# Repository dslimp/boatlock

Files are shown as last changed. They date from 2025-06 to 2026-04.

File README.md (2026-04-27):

# BoatLock

BoatLock is an ESP32-S3 anchor-hold controller with a Flutter companion app.
The current development target is a single bench board running the main anchor
runtime, BLE phone control, onboard BNO08x heading, GNSS telemetry, manual
deadman control, hardware setup, and BLE OTA firmware update flows.

Current firmware release: `0.2.0`

## What It Does

- Saves the current GNSS position as an anchor point.
- Holds position around the saved point using GNSS distance and onboard BNO08x
  heading.
- Supports phone manual control through the same deadman path planned for a
  future external BLE controller.
- Drives the thruster with PWM plus two direction pins.
- Drives steering through a DRV8825-compatible STEP/DIR driver.
- Streams compact BLE telemetry to the app and mirrors firmware logs over the
  BLE log characteristic.
- Supports hardware setup operations from the app: stepper tuning, compass
  controls, and BLE OTA firmware update.
- Provides deterministic on-device HIL scenarios (`SIM_*`, `S0..S19`) for
  regression checks without relying on live sensors.

The BLE protocol is documented in [docs/BLE_PROTOCOL.md](docs/BLE_PROTOCOL.md).

## Repository Layout

- `boatlock/` - ESP32-S3 firmware, built with PlatformIO.
- `boatlock_ui/` - Flutter app for Android, macOS, and other Flutter targets.
- `docs/` - protocol, hardware, release, and powered-bench notes.
- `tools/hw/nh02/` - tracked hardware-bench wrappers for flashing, OTA, and
  Android BLE smoke checks.
- `tools/android/` - Android app build and smoke helpers.
- `tools/sim/` - offline anchor simulation harness.

## Current Bench Hardware

`boatlock/main.cpp` is the source of truth for the active pinout.

| Function | ESP32-S3 pin | Notes |
| --- | ---: | --- |
| GPS RX | GPIO17 | connect GPS TX |
| GPS TX | GPIO18 | connect GPS RX |
| BNO08x UART-RVC RX | GPIO12 | connect BNO08x RVC TX/SDA |
| BNO08x reset | GPIO13 | firmware reset pulse |
| BNO08x P0/PS0 | 3V3 | selects UART-RVC |
| BNO08x P1/PS1 | GND | selects UART-RVC |
| Thruster PWM | GPIO7 | PWM output |
| Thruster direction | GPIO8, GPIO10 | H-bridge direction inputs |
| Steering DRV8825 STEP | GPIO6 | STEP input |
| Steering DRV8825 DIR | GPIO16 | DIR input |
| BOOT anchor-save button | GPIO0 | debounced long-press |
| STOP button | GPIO15 | hardware stop / pairing window |

The steering geometry is set for the Vanchor gearbox:

- motor steps per revolution: `200`
- gearbox ratio: `36:1`
- output steps per steering revolution: `7200` (default)
- default `StepMaxSpd`: `1200`
- default `StepAccel`: `800`

Adjust `StepSpr` in firmware settings for DRV8825 microstepping (`7200 × microstep factor`).

If the DRV8825 `MODE0/MODE1/MODE2` pins are strapped for microstepping, the
mechanical speed is divided by that microstep factor unless the geometry and
speed limits are intentionally retuned.

Complete the powered checks before connecting real motor load:

- [docs/POWERED_BENCH_CHECKLIST.md](docs/POWERED_BENCH_CHECKLIST.md)
- [docs/STEERING_DRIVER_INTAKE.md](docs/STEERING_DRIVER_INTAKE.md)
- [docs/BRUSHED_MOTOR_DRIVER_INTAKE.md](docs/BRUSHED_MOTOR_DRIVER_INTAKE.md)

## Firmware Build

Use PlatformIO from `boatlock/`.

```bash
cd boatlock
pio run -e esp32s3
```

Useful environments:

- `esp32s3` - normal firmware. It includes BLE OTA and setup commands.
- `esp32s3_acceptance` - bench acceptance firmware with dev/HIL sensor
  injection enabled.
- `esp32s3_bno08x_sh2_uart` - explicit SH2-UART compass target when that wiring
  is under test.

## Flashing And OTA

Normal firmware update for the moved hardware is phone-bridged BLE OTA through
the production app:

```bash
cd boatlock
pio run -e esp32s3
cd ..
tools/hw/nh02/android-run-app-check.sh \
  --ota \
  --ota-firmware boatlock/.pio/build/esp32s3/firmware.bin \
  --wait-secs 1800
```

Use the longer OTA wait when BLE discovery may be cold. The wrapper timeout
starts before scan/connect and can otherwise expire during an active transfer.

USB flash on the `nh02` bench is the seed/recovery path:

```bash
tools/hw/nh02/flash.sh
```

## Flutter App

The app wrappers build one release app. Setup controls are part of that app and
stay hidden during normal use; open Settings and enable `Настройка оборудования`
to show stepper tuning, compass rows, and firmware OTA.

Android build:

```bash
tools/android/build-app-apk.sh
```

macOS build:

```bash
tools/macos/build-app.sh
```

Run from source:

```bash
cd boatlock_ui
flutter pub get
flutter run
```

## Validation

Firmware tests:

```bash
cd boatlock
platformio test -e native
```

Flutter checks:

```bash
cd boatlock_ui
flutter test
flutter analyze
```

High-signal targeted checks used during bench work:

```bash
cd boatlock
platformio test -e native -f test_settings -f test_runtime_ble_command_log -f test_ble_command_handler -f test_stepper_control -f test_runtime_motion

cd ../boatlock_ui
flutter test test/settings_page_test.dart
flutter test test/settings_page_setup_ui_test.dart
```

Android production-app manual smoke on `nh02`:

```bash
tools/hw/nh02/android-run-app-check.sh --manual --wait-secs 130
```

This sends zero-throttle `MANUAL_TARGET`, observes `MANUAL`, sends `MANUAL_OFF`,
and verifies the firmware returns to a quiet mode. It is not a powered thrust
test.

## Runtime Rules

- Heading comes only from onboard BNO08x UART-RVC frames.
- Control GNSS is hardware GPS only; phone GPS is telemetry/UI fallback and does
  not pass the anchor-control quality gate.
- `ANCHOR_ON` requires a saved anchor point, fresh onboard heading, and GNSS
  quality.
- Manual control uses atomic `MANUAL_TARGET:<angleDeg>,<throttlePct>,<ttlMs>`
  plus `MANUAL_OFF`, with `angleDeg=-90..90` across the steering arc.
- Runtime faults and STOP enter safe quiet output; they do not automatically
  resume Anchor or Manual.
- BLE security is owner-secret based; paired devices must wrap control commands
  in `SEC_CMD`.

## License

This project is licensed under the terms of the [MIT License](LICENSE).

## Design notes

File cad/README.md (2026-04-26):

# BoatLock CAD

This directory contains printable and inspectable mechanical models for
BoatLock bench and ground-simulator hardware.

## FreeCAD MCP

BoatLock CAD work uses the `neka-nat/freecad-mcp` server:

- MCP package: <https://github.com/neka-nat/freecad-mcp>
- FreeCAD addon path on this workstation:
  `~/Library/Application Support/FreeCAD/v1-1/Mod/FreeCADMCP`
- RPC endpoint when FreeCAD is running: `127.0.0.1:9875`
- Codex MCP server command: `/Users/user/.local/bin/uvx freecad-mcp`

FreeCAD must be running for MCP operations that inspect or mutate the live
model. The addon settings should keep `auto_start_rpc=true`; verify with:

```bash
python3 tools/cad/freecad_mcp_smoke.py
```

Headless, repeatable exports should stay script-driven and committed next to
the model source. For the ground trike:

```bash
cad/ground_trike/export_freecad.sh
```

## Modeling Rules

- Keep source models in text form where practical: FreeCAD Python, OpenSCAD, or
  small structured config files.
- Generated `.FCStd`, STL, screenshots, and temporary mesh outputs belong under
  each model's `out/` directory unless they are intentionally promoted.
- Model load paths explicitly: wheel loads should go into axles, bearings,
  forks, brackets, and deck screws, not motor shafts or printed cosmetic ribs.
- Include reference solids for motors, wheels, bearings, screws, shafts, and
  steering stops before treating a model as printable.
- Print/export scripts must report dimensions and solid-count checks.

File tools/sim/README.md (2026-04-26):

# Anchor Simulator

`tools/sim` provides an offline simulation harness for Anchor control hardening.

## What it does

- feeds synthetic GNSS measurements (`lat/lon/time/hdop/sats`) into control logic
- computes control outputs (`thrust_pct`, heading alignment effects)
- simulates boat drift and actuator response
- reports quality metrics:
  - `time_in_deadband_pct`
  - `p95_error_m`
  - `max_error_m`
  - `p95_heading_error_deg`
  - `max_heading_error_deg`
  - `p95_yaw_rate_dps`
  - `max_yaw_rate_dps`
  - `p95_heading_inertia_lag_deg`
  - `p95_environment_yaw_accel_dps2`
  - `steering_jammed_time_pct`
  - `steering_backlash_crossings_per_min`
  - `thrust_while_misaligned_time_pct`
  - `control_saturation_time_pct`
  - `num_thrust_direction_changes_per_min`
  - `invalid_thrust_count`
  - `invalid_motor_count`
  - `invalid_distance_count`
  - `min_battery_voltage_v`
  - `max_motor_current_a`
  - `max_motor_temp_c`
  - `motor_current_limited_time_pct`
  - `motor_thermal_derated_time_pct`
  - `motor_driver_deadband_time_pct`
  - `wake_event_time_pct`
  - `chop_event_time_pct`
  - `wake_event_count`
  - `chop_event_count`

## Actuator Model

The simulator keeps the controller command (`thrust_pct`) separate from applied
thrust. Steering/yaw and applied thrust pass through offline actuator models.
The steering model supports:

- finite steering response rate
- backlash on steering reversal
- static wrong-zero offset
- scheduled jam windows

Heading changes then pass through a yaw-rate state with acceleration limiting,
damping, and environmental yaw acceleration. This keeps steering commands from
turning the simulated boat instantly and lets off-axis wind/current/wake/chop
forcing perturb heading without changing firmware runtime behavior.

Applied thrust passes through a brushed motor model with:

- driver deadband
- first-order motor response
- battery voltage sag from internal resistance
- current limiting
- thermal accumulation, cooling, and derating

## Catalog World Model

Data-backed scenarios can include a `boat` block with loaded mass, submerged
drag, and above-water windage inputs. Current and wind/gust forcing use a
quadratic drag approximation, then divide force by loaded mass to get
acceleration. Wave forcing remains a bounded disturbance term scaled by loaded
mass until water-log data exists. Scenario `environment.events` can add explicit
`wake` or `chop` packets with start time, duration, height, period, and
direction; reports expose their event time/count and yaw/rocking effects.

## Scenarios (minimum set)

1. `calm_good_gps`
2. `constant_current`
3. `gusts`
4. `wake_steering_backlash`
5. `short_steep_chop`
6. `gnss_dropout`
7. `poor_hdop`
8. `position_jumps`
9. `comm_loss`
10. `nan_data`

## Optional RF Water Scenarios

The `russian` scenario set normalizes the first slice of
`tools/sim/research/environment_inputs.*` into runnable profiles:

1. `river_oka_normal_55lb`
2. `volga_spring_flow_80lb`
3. `rybinsk_fetch_55lb`
4. `ladoga_storm_abort`
5. `baltic_gulf_drift`

These scenarios add current, wind/gusts, wave-induced forcing, explicit wake or
chop event packets, and rocking/yaw metrics. Their reports also include the
loaded boat mass, water drag, and windage inputs used by the world model.
`ladoga_storm_abort` is intentionally modeled as an environment-abort case, not
as a normal anchor-hold success case.

Normalized scenario inputs live in
`tools/sim/scenarios/environment_profiles.json`. The research files under
`tools/sim/research/` remain source material and should not be treated as
directly executable simulator configuration.

Each normalized data-backed scenario includes a `provenance` object with the
source file, source candidate id, and confidence label. `run_sim.py` copies that
object into each matching JSON report result; built-in core scenarios omit it.

Known remaining gaps:

- hardware calibration after powered bench and water logs exist

## Run locally

```bash
python3 tools/sim/test_sim_core.py
python3 tools/sim/run_sim.py --check --json-out tools/sim/report.json
python3 tools/sim/run_sim.py --scenario-set russian --check --json-out tools/sim/russian_report.json
python3 tools/sim/test_soak.py
python3 tools/sim/run_soak.py --hours 6 --check --json-out tools/sim/soak_report.json
```

`--check` exits non-zero if scenario thresholds are violated (for CI gate).

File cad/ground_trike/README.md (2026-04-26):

# BoatLock Ground Trike Simulator V0

This is a first-pass printable CAD concept for a small ground simulator:

- two passive rear wheels
- one front wheel that steers and drives
- NEMA17 steering motor on the fixed deck
- 8 mm steering kingpin carried by two 608 bearings
- front drive motor mounted on the rotating fork

The model is intentionally parametric and conservative. It is not tied to a
specific purchased wheel or gearmotor yet. The FreeCAD script is the primary
source for generated `.FCStd` and STL artifacts; the OpenSCAD file is kept as a
simple text fallback.

## Drive Choice

Default CAD assumption: a 25GA / 25D class 12 V metal gearmotor mounted on the
front fork, driving the front wheel axle through a small belt or spur stage.

That is preferable to hanging the wheel directly on the motor shaft: the wheel
load goes into a 6 mm axle and fork bearings/holes, while the motor only
provides torque. A cheap TT motor can move a light bench model, but it is loose
and weak for a useful BoatLock simulator.

Suggested first motor class:

- 25GA370 or 25D metal gearmotor
- 12 V
- 100-200 rpm with a 65-80 mm rubber wheel
- encoder optional, not required for the current BoatLock manual drive path

The front motor wires need a slack service loop. Do not use unlimited steering;
limit the front fork mechanically to about +/-100 degrees unless a slip ring is
added.

## Steering Stack

The NEMA17 is fixed to the deck and should only transmit steering torque.
The front wheel load is not meant to go through the NEMA17 shaft.

Stack from top to bottom:

1. NEMA17 on deck, 31 mm M3 pattern
2. 5 mm to 8 mm shaft coupler
3. 8 mm steel kingpin or shoulder bolt
4. two 608 bearings in the printed carrier
5. printed front fork clamped to the kingpin

## FreeCAD Export

The FreeCAD path is primary for this model. It can be driven directly by
`freecadcmd` for repeatable exports, or through the repo-enabled FreeCAD MCP
server for live model inspection and iteration.

```bash
./export_freecad.sh
```

Outputs:

- `out/boatlock_ground_trike.FCStd`
- `out/stl/deck_plate.stl`
- `out/stl/steering_bearing_carrier.stl`
- `out/stl/front_fork_25ga.stl`
- `out/stl/rear_axle_block.stl`
- `out/stl/motor_cap_25ga.stl`

The `.FCStd` contains the assembly with translucent reference solids for the
front wheel, rear wheels, NEMA17, and front 25GA motor. The STL files are
exported as individual printable parts.

## OpenSCAD Fallback

Open `boatlock_ground_trike.scad` and set `part` to one of:

- `assembly`
- `deck_plate`
- `steering_bearing_carrier`
- `front_fork_25ga`
- `rear_axle_block`
- `motor_cap_25ga`

Export examples:

```bash
mkdir -p stl
openscad -o stl/deck_plate.stl -D 'part="deck_plate"' boatlock_ground_trike.scad
openscad -o stl/steering_bearing_carrier.stl -D 'part="steering_bearing_carrier"' boatlock_ground_trike.scad
openscad -o stl/front_fork_25ga.stl -D 'part="front_fork_25ga"' boatlock_ground_trike.scad
openscad -o stl/rear_axle_block.stl -D 'part="rear_axle_block"' boatlock_ground_trike.scad
openscad -o stl/motor_cap_25ga.stl -D 'part="motor_cap_25ga"' boatlock_ground_trike.scad
```

## Print Notes

- Print in PETG, ASA, PA, or PA-CF. Avoid PLA for the steering fork if it will
  see vibration, heat, or repeated crashes.
- Drill/ream functional holes after printing.
- Use M3 heat-set inserts or through screws with nuts for serviceable joints.
- Sand the 608 bearing pockets to fit the exact bearings.
- Print the front fork with enough perimeters that axle and kingpin holes are
  surrounded by solid material.

## BoatLock Firmware Caveat

This CAD switches the steering concept from the current 28BYJ-48 / ULN2003
bench path to NEMA17 mechanics. A normal NEMA17 driver path is not a drop-in
replacement for the current firmware wiring. Before connecting a powered NEMA17
driver, add and validate the real steering driver path in firmware and bench
acceptance.

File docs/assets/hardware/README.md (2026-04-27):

# Hardware Reference Images

These images are checked in so BoatLock pin assignments can be checked without
reopening the vendor page.

- `esp32-s3-lcd-2-pin-definition.png`: Waveshare ESP32-S3-LCD-2 header pinout.
- `esp32-s3-lcd-2-resource-introduction.png`: Waveshare ESP32-S3-LCD-2 onboard
  resources, including the microSD slot.

Source: Waveshare ESP32-S3-LCD-2 wiki/product material.

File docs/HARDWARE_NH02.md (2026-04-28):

# NH02 Hardware Bench

`nh02` (`192.168.88.61`) is the hardware bench host for the ESP32-S3 stand with GPS, display, compass, and stepper connected over USB.

## Board Reference

The current bench board is the Waveshare ESP32-S3-LCD-2 class board. Local
copies of the vendor pinout/resource images are kept under
`docs/assets/hardware/` so hardware checks do not depend on finding the product
page again.

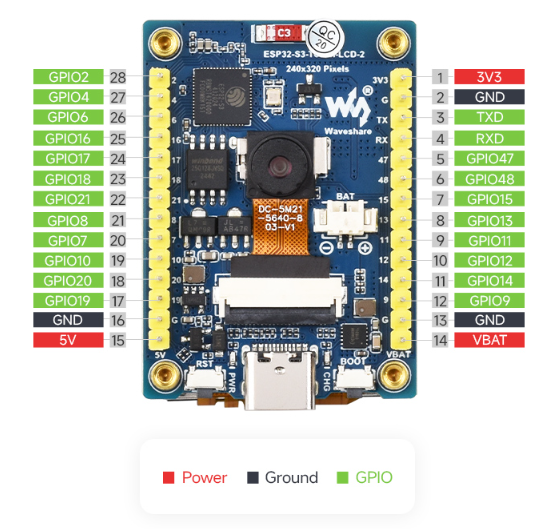
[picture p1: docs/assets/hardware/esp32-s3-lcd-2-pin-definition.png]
ESP32-S3-LCD-2 pin definition


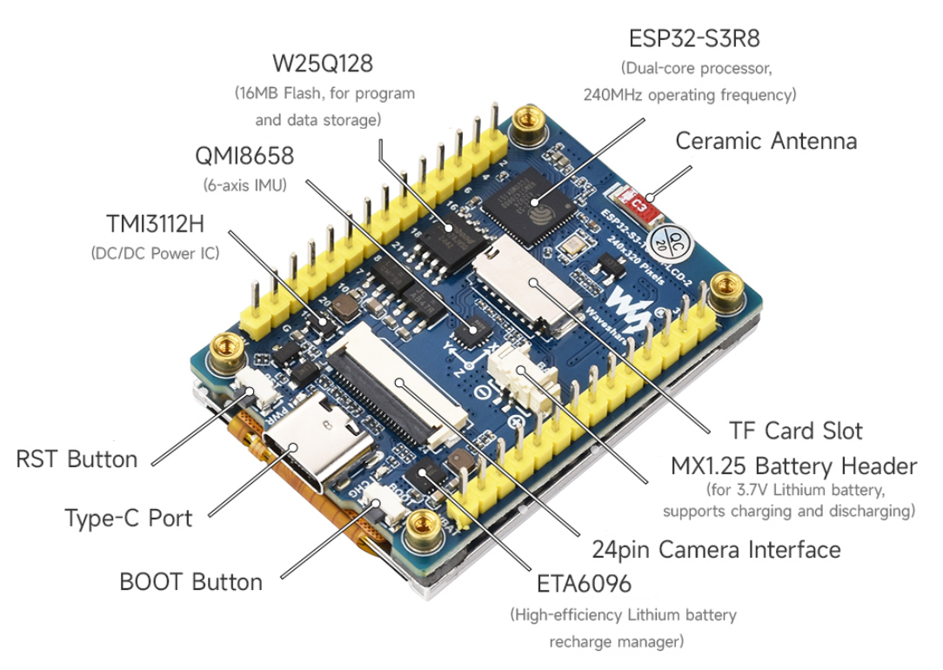
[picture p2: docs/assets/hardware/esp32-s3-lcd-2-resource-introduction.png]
ESP32-S3-LCD-2 resource introduction


## MicroSD runtime logging

- The onboard microSD slot is used for water-debug capture when a FAT-formatted
  card is inserted.
- Firmware writes JSONL files under `/boatlock/blNNNNN.jsonl`.
- Each file rotates at approximately `8 MiB`.
- If free space drops below approximately `8 MiB`, older BoatLock log files are
  deleted until approximately `16 MiB` is free or only the active file remains.
- Records include `type=session`, `type=log`, and 5 Hz `type=nav` snapshots with
  GNSS, heading, speed, anchor state, mode/status, motor, stepper, BLE, and
  `sd_dropped` counters.
- SD failure must not block control. The logger uses a bounded RAM queue and
  drops old lines when the card is absent, slow, or full.

## Remote runtime

- Remote USB device:
  - `/dev/serial/by-id/usb-Espressif_USB_JTAG_serial_debug_unit_98:88:E0:03:BA:5C-if00`
- Remote tool runtime:
  - `/opt/boatlock-hw/.venv`
- Remote runtime root:
  - `/opt/boatlock-hw`
- Remote RFC2217 service:
  - `boatlock-esp32s3-rfc2217.service`
- RFC2217 URL:
  - `rfc2217://192.168.88.61:4000?ign_set_control`

## Change boundary on nh02

- BoatLock-owned host changes are limited to:
  - `/opt/boatlock-hw/`
  - `/etc/systemd/system/boatlock-esp32s3-rfc2217.service`
- Android USB validation on `nh02` may additionally install the Ubuntu `adb` package through the tracked remote helper when that workflow is explicitly used.
- `install.sh` must be rerun after changing the tracked service or remote flash helper.
- `install.sh` must also be rerun after changing tracked remote Android helpers.
- `install.sh` restarts only `boatlock-esp32s3-rfc2217.service`; it does not touch unrelated services on `nh02`.

## Local workflow

- Install or refresh the remote bench runtime:
  - `tools/hw/nh02/install.sh`
- Bench moved-hardware OTA proof through the phone BLE bridge:
  - `tools/hw/nh02/deploy.sh`
  - this builds `esp32s3`, builds the ordinary release APK, refreshes Android helpers only, installs that exact APK, serves `firmware.bin`, uploads over BLE OTA, and waits for telemetry recovery
- Reuse already-built firmware/APK through the same bench automation path:
  - `tools/hw/nh02/deploy.sh --no-build`
- Seed or recover over USB through `nh02`:
  - `tools/hw/nh02/flash.sh`
- Flash the dev/HIL acceptance profile through `nh02`:
  - `tools/hw/nh02/flash.sh --profile acceptance`
- Build a firmware binary for BLE OTA:
  - `cd boatlock && pio run -e esp32s3 && shasum -a 256 .pio/build/esp32s3/firmware.bin`
- Upload firmware without ESP32 USB:
  - copy `firmware.bin` to the phone and use Settings -> `Файл на телефоне`, or
    publish a GitHub Release and use Settings -> `Последняя с GitHub`
- Low-level phone-bridged BLE OTA app-check, used by `deploy.sh`:
  - `tools/hw/nh02/android-run-app-check.sh --ota --ota-firmware boatlock/.pio/build/esp32s3/firmware.bin --wait-secs 1800`
- Public GitHub latest-release OTA app-check, same source as Settings -> `Последняя с GitHub`:
  - `tools/hw/nh02/android-run-app-check.sh --ota-latest-release --wait-secs 1800`
- Flash the current build without rebuilding:
  - `tools/hw/nh02/flash.sh --no-build`
- Run post-flash hardware acceptance:
  - `tools/hw/nh02/acceptance.sh`
- Run acceptance without forcing a reset first:
  - `tools/hw/nh02/acceptance.sh --no-reset`
- Open the serial monitor through RFC2217:
  - `tools/hw/nh02/monitor.sh`
- Check bridge/device status on the bench host:
  - `tools/hw/nh02/status.sh`
- Install or refresh Android USB tooling on `nh02`:
  - `tools/hw/nh02/android-install.sh`
- Check Android USB and `adb` visibility on `nh02`:
  - `tools/hw/nh02/android-status.sh`
- Install the normal production app APK on the `nh02` phone:
  - `tools/hw/nh02/android-install-app.sh`
- Enable Android ADB over Wi-Fi after initial USB discovery:
  - `tools/hw/nh02/android-wifi-debug.sh`
- Android smoke/check wrappers use ADB Wi-Fi by default when no `--serial` is
  passed. Set `BOATLOCK_NH02_ANDROID_WIFI_ADB=0` to force the default `adb`
  target selection.
- Build, install/update, and run the Android BLE smoke app through `nh02`:
  - `tools/hw/nh02/android-run-smoke.sh`
- Build, install/update, and run the Android BLE reconnect smoke app through `nh02`:
  - `tools/hw/nh02/android-run-smoke.sh --reconnect --wait-secs 130`
- Build, install/update, and prove phone recovery after ESP32 reboot:
  - `tools/hw/nh02/android-run-smoke.sh --esp-reset --wait-secs 130`
- Build, install/update, and prove compass calibration command delivery:
  - `tools/hw/nh02/android-run-app-check.sh --compass --wait-secs 130`
- Build, install/update, and prove BLE-visible hardware GPS fix:
  - `tools/hw/nh02/android-run-app-check.sh --gps --wait-secs 180`
- Run the full standard on-device HIL suite on the bench using the normal
  release firmware profile:
  - `tools/hw/nh02/run-sim-suite.sh`
- Run the smoke app without reinstalling the APK:
  - `tools/hw/nh02/android-run-smoke.sh --no-install`

## Profile-Aware Gate

Firmware command-scope enforcement is implemented in the shared BLE command
path. The normal `esp32s3` firmware accepts release commands, including setup,
BLE OTA, and `SIM_*`. The `esp32s3_acceptance` firmware additionally accepts
dev/HIL sensor injection such as `SET_PHONE_GPS`.

The effective firmware profile must stay visible at every bench entry point:

- USB flash wrappers must print the effective PlatformIO environment and
  command-scope profile.
- `tools/hw/nh02/flash.sh` accepts the normal `esp32s3` environment by default
  and `--profile acceptance` only when dev/HIL injection is required.
- `tools/hw/nh02/acceptance.sh` must know which profile is flashed. Normal
  acceptance keeps `SIM_*`, setup, and BLE OTA available while external
  sensor-injection commands stay gated.
- `tools/hw/nh02/android-run-app-check.sh --ota` runs against the normal firmware
  and must prove post-update telemetry recovery.
- `tools/hw/nh02/android-run-app-check.sh --sim`, `--sim-suite`, and the smoke
  `sim` mode run against the normal firmware.
- `tools/hw/nh02/run-sim-suite.sh` is the standard full on-device HIL bench
  gate. It flashes the normal firmware, runs boot acceptance, then runs
  production-app `sim_suite`.
- `tools/hw/nh02/install.sh` must be rerun after changing any tracked remote
  helper that enforces or reports the selected profile.

Accepted flash profile selector:

- `--profile acceptance` or `BOATLOCK_PIO_ENV=acceptance` builds
  `esp32s3_acceptance`.

Accepted direct PlatformIO environments:

- `esp32s3`: normal firmware with setup, BLE OTA, and release commands.
- `esp32s3_acceptance`: bench profile with dev/HIL sensor injection enabled.
- `esp32s3_bno08x_sh2_uart`: normal command profile with SH2-UART compass
  support.
- `gpio_probe` and `uart_rvc_probe_rx12`: debug probe builds, not release
  artifacts.

`BOATLOCK_PIO_ENV` must name one of the accepted selectors above. An empty or
unknown value is a wrapper error and must not silently fall back to another
build.

Expected operator flow:

1. Use phone BLE OTA as the normal moved-hardware update path; use USB flash
   only to seed/recover the device.
2. Run USB-bench water-readiness checks against the normal firmware and verify
   external-injection commands are rejected without actuation.
3. Run phone BLE OTA proof with `tools/hw/nh02/deploy.sh`.
4. Run quick on-device HIL on the normal firmware with the standard `nh02`
   acceptance plus Android `sim` smoke/check path.
5. For the standard full on-device HIL suite, run
   `tools/hw/nh02/run-sim-suite.sh`; it flashes and validates the normal
   firmware before the suite.
6. Use `--profile acceptance` only when a test explicitly needs dev/HIL
   injection, then return to the normal firmware.

If `OTA_BEGIN` or `SIM_RUN` appears broken, check the printed profile first; the
wrappers are expected to fail loudly instead of silently running the wrong
profile.

## USB Seed/Recovery Deploy Path

1. Local `pio run -e esp32s3` builds the firmware.
2. `flash.sh` copies `bootloader.bin`, `partitions.bin`, and `firmware.bin` to `nh02`.
3. Remote helper `/opt/boatlock-hw/bin/boatlock-flash-esp32s3.sh` temporarily stops the RFC2217 bridge, flashes the ESP32-S3 with remote `esptool`, then starts the bridge again.
4. `acceptance.sh` optionally forces a clean reset, captures boot logs over RFC2217, checks required boot markers, and fails on fatal log patterns.

## BLE OTA Phone Bridge

1. Use this as the normal moved-hardware firmware update path after the ESP32 already runs firmware with BLE OTA support.
2. Seed or recover over USB only when the target lacks an OTA-capable image or cannot reconnect over BLE.
3. Operator path A: copy the built `firmware.bin` to the phone and use Settings -> `Файл на телефоне`.
4. Operator path B: publish a GitHub Release with `manifest.json` and `firmware-esp32s3.bin`, then use Settings -> `Последняя с GitHub`.
5. For a local file, the app computes SHA-256 before transfer. For GitHub, the app downloads and verifies the release manifest SHA-256 before transfer.
6. The app sends `OTA_BEGIN`, writes chunks to BLE characteristic `9abc`, then sends `OTA_FINISH`.
7. ESP32 validates byte count and SHA-256 before finalizing the OTA partition and rebooting. Disconnect or failed validation aborts without changing the active boot partition.
8. Bench automation may still use hidden URL/SHA runtime extras with `tools/hw/nh02/deploy.sh`; that is a validation shortcut only, not an operator UI path.
   The wrapper builds the normal firmware and ordinary release APK, refreshes Android helpers without requiring ESP32 USB, installs the exact APK, serves `firmware.bin` on `nh02`, exposes it to the phone with `adb reverse`, starts its runtime OTA check, and waits for post-reboot telemetry.
   When `--serial` is omitted, the wrapper enables and uses Android ADB Wi-Fi
   automatically.
9. Current BLE upload requests high connection priority, a larger MTU, and
   write-without-response for OTA chunks when Android and the characteristic
   support it; otherwise it falls back to acknowledged writes. Keep the wrapper
   timeout long enough for the slower fallback path.
10. After a successful `OTA_FINISH` write, ESP32 may reboot before the phone
   receives the `[OTA] finish ok` notify line. Treat the post-finish disconnect
   plus reconnect/telemetry recovery as the bench verdict; the log line is useful
   evidence when present, not the only success signal.
11. Do not keep ESP32 debug Wi-Fi OTA running as the normal persistent bench
    channel while BLE is active. On this ESP32-S3/Arduino/NimBLE stack,
    Wi-Fi+BLE coexistence requires Wi-Fi modem sleep and was not reliable enough
    for firmware flashing. Use Android ADB Wi-Fi to control the phone and BLE OTA
    from the phone to flash the ESP32.
12. The BLE log characteristic `78ab` mirrors firmware `logMessage()` serial
    lines generated while the phone is connected and subscribed, including
    `[BLE]` lines. Boot logs before a BLE connection still require RFC2217/USB
    serial capture.

## Android USB Path

1. Rerun `tools/hw/nh02/install.sh` after changing tracked Android helpers.
2. `tools/hw/nh02/android-install.sh` ensures `adb` exists on `nh02`.
3. `tools/hw/nh02/android-status.sh` checks whether the phone is visible over USB and whether `adb devices -l` sees it.
4. `tools/hw/nh02/android-install-app.sh` builds, copies, and installs the normal production app APK on the `nh02` phone without running a smoke/check probe.
5. `tools/hw/nh02/android-wifi-debug.sh` can switch the same phone to ADB TCP/IP and prints `android_wifi_serial=<ip>:5555`.
6. `tools/hw/nh02/android-run-smoke.sh` and
   `tools/hw/nh02/android-run-app-check.sh` call the Wi-Fi ADB helper
   automatically unless `BOATLOCK_NH02_ANDROID_WIFI_ADB=0` is set or an explicit
   `--serial` is passed.
7. Any Android smoke wrapper can still use explicit `--serial <ip>:5555` to
   prove install/logcat/debug control over Wi-Fi instead of USB.
8. `tools/hw/nh02/android-run-smoke.sh` copies the ordinary release app APK to `nh02`, installs or updates it with remote `adb`, launches a runtime check in the app, and waits for the `BOATLOCK_SMOKE_RESULT` log line.
9. `tools/hw/nh02/android-run-smoke.sh --reconnect --wait-secs 130` additionally waits for first telemetry, cycles phone Bluetooth through ADB, and requires telemetry recovery without restarting the app.
10. `tools/hw/nh02/android-run-smoke.sh --esp-reset --wait-secs 130` waits for first telemetry, resets the ESP32-S3 with the tracked remote reset helper, and requires telemetry recovery without restarting the app.
11. `tools/hw/nh02/android-run-app-check.sh --compass --wait-secs 130` sends safe compass setup commands (`COMPASS_CAL_START`, `COMPASS_DCD_AUTOSAVE_OFF`, `COMPASS_DCD_SAVE`) and requires device log acknowledgements.
12. `tools/hw/nh02/android-run-app-check.sh --gps --wait-secs 180` waits for production-app BLE telemetry with non-zero valid coordinates and GNSS quality `>0`; this can run while ESP32 is powered away from USB if BLE remains reachable.
13. `tools/hw/nh02/android-run-app-check.sh --sim-suite --wait-secs 1800` runs `SIM_LIST`, every listed scenario through `SIM_RUN:<id>,0`, polls `SIM_STATUS`, collects `SIM_REPORT`, and fails on any `pass:false`.
14. `tools/hw/nh02/run-sim-suite.sh` wraps the full bench flow around `--sim-suite`: helper install, target proof, release flash, boot acceptance, and production-app suite run.
15. `tools/hw/nh02/deploy.sh` is bench automation for firmware+APK OTA proof and verifies phone download, SHA-256 check, BLE upload, ESP32 reboot, and app telemetry recovery. Use `tools/hw/nh02/android-run-app-check.sh --ota --ota-firmware boatlock/.pio/build/esp32s3/firmware.bin --wait-secs 1800` only as the lower-level local-firmware OTA check. Use `tools/hw/nh02/android-run-app-check.sh --ota-latest-release --wait-secs 1800` to prove the public GitHub Release source used by the phone button.
16. If the phone appears only as `MTP` or a vendor USB device and not in `adb devices`, the cable path is alive but USB debugging is still off on the phone.
17. Status smoke recovery may clear `STOP_CMD` directly to `IDLE/WARN` after a
    zero-throttle manual recovery command without exposing a visible `MANUAL`
    telemetry frame. The wrapper must still send `MANUAL_OFF` cleanup and accept
    the recovered non-alert state.

## Xiaomi Install Note

- On the current Xiaomi test phone, the first `adb install` was blocked by MIUI policy with `INSTALL_FAILED_USER_RESTRICTED`.
- The tracked `adb install -r` update path succeeded after the phone-side MIUI flow was satisfied: Xiaomi account, inserted SIM card, and `Install via USB` approval.
- Treat first-install policy and later USB update as separate checkpoints; do not assume the first failure means all future `adb install -r` updates are blocked.

## Bench Bridge Path

- Runtime logs go through the persistent RFC2217 bridge on `nh02`.
- `monitor.sh` uses local `pyserial-miniterm` against the RFC2217 endpoint.
- If the monitor path fails, inspect `status.sh` before touching the USB device manually.
- BLE OTA through the phone is the normal no-USB firmware update path after the
  first OTA-capable image is present.
- Local phone-file OTA computes SHA-256 in the app before transfer. GitHub OTA
  verifies the release manifest SHA-256 before transfer. Do not add
  operator-facing arbitrary URL/SHA fields back to the Settings UI.
- The app wrappers build one release Android/macOS app. Setup controls are in
  that app and hidden behind the Settings `Настройка оборудования` switch. The
  one-button release OTA path resolves firmware through the latest GitHub
  Release for `dslimp/boatlock`. Local wrapper shortcuts:
  `tools/android/build-app-apk.sh` and `tools/macos/build-app.sh`.
- CI publishes one ready-to-install app artifact per platform:
  `flutter-android-apk/boatlock-app.apk` and
  `flutter-macos-app/boatlock-macos.zip`.
- macOS app local acceptance is covered by
  `tools/macos/acceptance.sh`. Use `--static-only` for bundle/signature/
  entitlement checks, `--artifact-zip boatlock-macos.zip` for a CI
  artifact, and `--manual` to open the app with the update checklist.
  Without BLE hardware this proves only bundle/runtime readiness, not OTA.
- Android app checks exercise the public GitHub latest-release path with
  `tools/hw/nh02/android-run-app-check.sh --ota-latest-release --wait-secs 1800`.
  This starts the normal app with runtime check extras and lets the app fetch
  `manifest.json` plus `firmware-esp32s3.bin` from the latest GitHub Release.
  Adding `--ota-firmware boatlock/.pio/build/esp32s3/firmware.bin` switches the
  same check into local temporary-manifest validation for unpublished firmware.
  Both modes still wait for post-reboot telemetry.
- Tagged releases publish `manifest.json` and `firmware-esp32s3.bin` with the
  same `esp32s3` and `release` constraints as the local manifest path. The
  fallback release metadata files are `BUILD_INFO-esp32s3.txt` and
  `SHA256SUMS-esp32s3.txt`.
- `tools/hw/nh02/flash.sh` stages `boot_app0.bin` and flashes it at `0xe000`, so a USB seed flash after prior OTA boots the freshly flashed `ota_0` image instead of a stale OTA slot.
- Keep the seed flash recoverable through USB. If a BLE OTA upload fails before `OTA_FINISH`, the current firmware remains active; if the app cannot reconnect, flash the normal firmware again through `tools/hw/nh02/flash.sh`.

## Compass Wiring

- Accepted bench compass transport is currently BNO08x UART-RVC.
- Current `nh02` wiring:
  - BNO08x `SDA/TX` -> ESP32-S3 `GPIO12`
  - BNO08x `RST` -> ESP32-S3 `GPIO13`
  - BNO08x `P0/PS0` -> `3V3`
  - BNO08x `P1/PS1` -> `GND`
  - UART baud `115200`
- SH2-UART DCD migration target:
  - BNO08x `TXO` -> ESP32-S3 `GPIO12`
  - BNO08x `RXI` -> ESP32-S3 `GPIO11`
  - BNO08x `RST` -> ESP32-S3 `GPIO13`
  - BNO08x `P0/PS0` -> `GND`
  - BNO08x `P1/PS1` -> `3V3`
  - build with `BOATLOCK_PIO_ENV=esp32s3_bno08x_sh2_uart`
- Full DCD/tare functionality is not accepted on the current RVC wiring. RVC can only prove command delivery with `ok=0`; SH2-UART acceptance needs the wiring above plus a fresh flash of the explicit SH2 target.
- `GPIO12` was verified by grounding the RX line and by reading live RVC frames with `uart_rvc_probe_rx12`.
- `GPIO13` was verified as reset by grounding the reset wire and watching `gpio_probe` transitions.
- Hardware acceptance requires `[COMPASS] ready=1 source=BNO08x-RVC rx=12 ... baud=115200` plus `[COMPASS] heading events ready`.
- The old ESP32-S3 I2C compass path is removed from production firmware. Historical failure notes are kept in `WORKLOG.md`, not as a fallback path.

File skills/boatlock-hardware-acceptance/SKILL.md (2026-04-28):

---
name: boatlock-hardware-acceptance
description: "Use for BoatLock real-hardware acceptance on nh02 after phone BLE OTA or recovery USB flashing, reading serial boot logs, checking sensor/bridge readiness, or preparing Android USB/BLE smoke tests against the hardware bench."
---

# BoatLock Hardware Acceptance

Use this skill when the task is about updating or validating the real ESP32-S3 hardware through phone BLE OTA, recovery USB flashing on `nh02`, or Android USB + BLE smoke against the bench.

## Read Only What You Need

- NH02 deploy/debug path and host boundary:
  - `docs/HARDWARE_NH02.md`
- Current BoatLock hardware/runtime invariants:
  - `skills/boatlock/references/firmware.md`
- BLE/app contract:
  - `skills/boatlock/references/ble-ui.md`
- Android USB + BLE workflow and current limits:
  - `references/android-ble.md`

## NH02 Acceptance Workflow

1. Refresh the bench runtime if tracked helpers or service units changed:
   - `tools/hw/nh02/install.sh`
2. Update current firmware when needed:
   - operator path A: Android Settings -> `Файл на телефоне`
   - operator path B: Android Settings -> `Последняя с GitHub`
   - bench automation path: `tools/hw/nh02/deploy.sh`
   - reuse already-built firmware/APK through the same path: `tools/hw/nh02/deploy.sh --no-build`
   - recovery/seed path only: `tools/hw/nh02/flash.sh` or `tools/hw/nh02/flash.sh --no-build`
3. Run hardware acceptance:
   - `tools/hw/nh02/acceptance.sh`
4. For microSD logger acceptance, insert a FAT-formatted card before boot and
   verify `[SD] logger ready=1`, display redraws, `/boatlock/*.jsonl` growth,
   and `sd_dropped` stays bounded under the expected log rate.
5. If acceptance fails, inspect:
   - `tools/hw/nh02/status.sh`
   - `tools/hw/nh02/monitor.sh`

## Android USB + BLE Smoke Workflow

1. Check USB device visibility:
   - `tools/android/status.sh`
   - or `tools/hw/nh02/android-status.sh` when the phone is attached to `nh02`
2. Optionally switch the phone to ADB Wi-Fi after USB proof:
   - `tools/hw/nh02/android-wifi-debug.sh`
   - Android smoke/check wrappers auto-enable and use ADB Wi-Fi when no
     `--serial` is passed; set `BOATLOCK_NH02_ANDROID_WIFI_ADB=0` only when USB
     `adb` must be forced.
3. Build the ordinary release app APK:
  - `tools/android/build-app-apk.sh`
4. Install and run the phone check flow through the same release app:
   - `tools/android/run-smoke.sh`
   - or `tools/hw/nh02/android-run-smoke.sh` when the phone is attached to `nh02`
   - use `tools/hw/nh02/android-run-app-check.sh --manual --wait-secs 130`, `--status`, `--anchor`, `--sim`, `--reconnect`, or `--esp-reset` for production-app command/recovery flows
   - use `tools/hw/nh02/android-run-app-check.sh --sim-suite --wait-secs 1800` to run all listed on-device HIL scenarios through the production app on an already-flashed release profile
   - use `tools/hw/nh02/run-sim-suite.sh` for the standard full bench gate; it installs helpers, proves targets, flashes normal firmware, runs boot acceptance and `sim_suite`
   - use `tools/hw/nh02/android-run-app-check.sh --compass --wait-secs 130` after compass BLE command changes; it sends safe DCD setup commands and requires device-log acknowledgements
   - use `tools/hw/nh02/android-run-app-check.sh --gps --wait-secs 180` after GNSS live-telemetry changes or field GPS checks; it requires valid non-zero coordinates and `gnssQ > 0`
   - use `tools/hw/nh02/deploy.sh` after BLE OTA/app-delivery changes; it builds the normal firmware and release APK, refreshes Android helpers, installs the same release app, serves `firmware.bin` from `nh02`, uploads over BLE from the phone, and requires post-reboot telemetry recovery
  - use `tools/hw/nh02/android-run-app-check.sh --ota-latest-release --wait-secs 1800` to prove the public GitHub Release button source through the production app
  - use `tools/hw/nh02/android-run-app-check.sh --ota --ota-firmware boatlock/.pio/build/esp32s3/firmware.bin` only as the lower-level local-firmware OTA check when you need to bypass the build wrapper
   - pass a longer OTA wait such as `--wait-secs 1800` when BLE discovery may
     be cold or intermittent; the wrapper timeout includes scan/reconnect time
     before upload starts and can otherwise expire during an active transfer
   - use `tools/hw/nh02/android-run-smoke.sh --manual --wait-secs 130` after manual BLE protocol changes; this sends zero-throttle `MANUAL_TARGET`, verifies `MANUAL`, sends `MANUAL_OFF`, and verifies mode exit
   - use `tools/hw/nh02/android-run-smoke.sh --status --wait-secs 130` after phone-visible status/severity changes; this sends `STOP`, verifies `ALERT/STOP_CMD`, then clears through zero-throttle manual roundtrip
   - use `tools/hw/nh02/android-run-smoke.sh --sim --wait-secs 130` after `SIM_*` BLE/HIL changes; this starts realtime `S0`, verifies `SIM` mode, sends `SIM_ABORT`, then clears the safe hold through zero-throttle manual recovery
   - use `tools/hw/nh02/android-run-smoke.sh --anchor --wait-secs 130` after phone-visible anchor command, safety gate, or anchor telemetry changes; this sends `ANCHOR_ON`, verifies the bench-side safety denial, sends `ANCHOR_OFF`, and verifies the device did not enter `ANCHOR`
   - use `tools/hw/nh02/android-run-smoke.sh --reconnect --wait-secs 130` when reconnect behavior is the acceptance target
   - use `tools/hw/nh02/android-run-smoke.sh --esp-reset --wait-secs 130` when ESP32 reboot recovery is the acceptance target
   - do not use `--no-install` as acceptance unless the user explicitly waives exact APK installation proof for that run
5. If it fails, inspect:
  - device logcat around `BOATLOCK_SMOKE_RESULT`
  - `tools/hw/nh02/monitor.sh`
  - `tools/hw/nh02/status.sh`
  - `tools/hw/nh02/android-status.sh` when the phone is attached to `nh02` instead of the local workstation

## What Acceptance Proves

- Boot log is reachable over the tracked debug path.
- Bench hardware reports:
  - `BNO08x-RVC` ready on `rx=12 baud=115200`
  - live BNO08x UART-RVC heading frames
  - BNO08x reset pin `13` pulse on boot/retry
  - display ready
  - NVS settings load
  - BLE init + advertising
  - stepper config
  - STOP button init
  - GPS UART activity
- Fatal boot indicators such as panic/assert/advertising failure, Arduino `[E]` logs, `COMPASS lost`, or `COMPASS retry ready=0` are not present in captured logs.
- Compass acceptance requires `[COMPASS] heading events ready`; `[COMPASS] ready=1 source=BNO08x-RVC ...` alone is not sufficient.
- Do not count `[COMPASS] reset ... pulse=1` as recovery proof. Recovery is proven only by fresh heading frames after the pulse and a clean long acceptance capture.
- For compass-focused changes, use a longer capture such as `--seconds 180`; a short boot-only pass can miss delayed wiring or frame-loss failures.
- microSD logger acceptance requires real media proof. Compile success and a
  boot log alone do not prove `/boatlock/*.jsonl` creation, write cadence,
  rotation, or low-space deletion.

## What Acceptance Does Not Prove

- It does not prove BLE control flow end to end.
- Basic Android smoke proves BLE scan/connect and telemetry with known current protocol mode/status values only; it does not intentionally send actuation commands.
- Manual Android smoke proves exact APK install, BLE scan/connect/telemetry, zero-throttle `MANUAL_TARGET`, observed `MANUAL` mode, `MANUAL_OFF`, and observed mode exit. It is not a powered thrust test.
- Status Android smoke proves exact APK install, BLE scan/connect/telemetry, safe `STOP` command delivery, observed `ALERT/STOP_CMD`, and alert recovery through zero-throttle manual roundtrip. Recovery may clear directly to a non-alert `IDLE/WARN` frame without an observed intermediate `MANUAL` frame; still require `MANUAL_OFF` cleanup. It is not a powered thrust test.
- SIM Android smoke proves exact APK install, BLE scan/connect/telemetry, `SIM_RUN:S0,1`, observed `SIM` mode, `SIM_ABORT`, observed mode exit, and alert recovery through zero-throttle manual roundtrip. It is not a powered thrust test.
- Anchor Android smoke proves exact APK install, BLE scan/connect/telemetry, `ANCHOR_ON` delivery, observed `[EVENT] ANCHOR_DENIED` from the bench safety gate, `ANCHOR_OFF` cleanup, and no transition into `ANCHOR`. It is not a real anchor-hold quality test.
- Reconnect Android smoke proves exact APK install, first telemetry, host-triggered Bluetooth outage, and telemetry recovery without app restart.
- ESP reset Android smoke proves exact APK install, first telemetry, ESP32 reset through the tracked reset helper, and telemetry recovery without app restart.
- Compass Android smoke proves exact APK install, first telemetry, safe compass calibration command delivery, and device-log acknowledgement. On RVC wiring it proves routing only; it does not prove DCD success.
- GPS Android smoke proves exact APK install, BLE scan/connect/telemetry, valid non-zero coordinates, and GNSS quality `>0`. It does not prove anchor-control GNSS gate readiness unless `gnssQ=2` and anchor-specific acceptance also passes.
- OTA production-app check proves exact APK install, phone HTTP download via `adb reverse`, SHA-256 verification in the app, BLE OTA upload, ESP32 reboot, and telemetry recovery after the update. A post-`OTA_FINISH` disconnect plus reconnect/telemetry is acceptable even if the app misses the `[OTA] finish ok` notify before reboot. It does not prove bootloader or partition-table changes; those still need USB flash.
- Persistent bench wireless is Android ADB Wi-Fi to the phone plus BLE to ESP32.
  Direct ESP32 debug Wi-Fi OTA is a boot-window/debug path, not the normal
  persistent channel while BLE is active on the ESP32-S3 bench.
- BLE log characteristic `78ab` mirrors firmware serial log lines generated
  after the phone is connected/subscribed, including `[BLE]` lines. Use
  RFC2217/USB serial for pre-BLE boot logs.
- Android smoke does not prove real powered actuation or on-water hold quality.
- Full BNO08x DCD/tare acceptance requires the explicit `esp32s3_bno08x_sh2_uart` target plus SH2-UART wiring; do not count current RVC acceptance as DCD proof.
- It does not prove real anchor hold quality on water.
- It does not replace on-device `SIM_*` checks or offline simulation.
- It does not prove durable water-debug logging unless the FAT microSD card is
  inserted and checked after runtime.

## Current Commands

- Bench runtime refresh:
  - `tools/hw/nh02/install.sh`
- BLE OTA bench automation:
  - `tools/hw/nh02/deploy.sh`
  - `tools/hw/nh02/deploy.sh --no-build`
- Low-level BLE OTA app-check:
  - `tools/hw/nh02/android-run-app-check.sh --ota --ota-firmware boatlock/.pio/build/esp32s3/firmware.bin --wait-secs 1800`
- Public GitHub latest-release app-check:
  - `tools/hw/nh02/android-run-app-check.sh --ota-latest-release --wait-secs 1800`
- USB seed/recovery flash:
  - `tools/hw/nh02/flash.sh`
- Acceptance:
  - `tools/hw/nh02/acceptance.sh`
  - `tools/hw/nh02/acceptance.sh --no-reset`
  - `tools/hw/nh02/acceptance.sh --seconds 15 --log-out /tmp/boatlock-boot.log --json-out /tmp/boatlock-acceptance.json`
- Debug:
  - `tools/hw/nh02/status.sh`
  - `tools/hw/nh02/monitor.sh`
- Android:
  - `tools/hw/nh02/android-install-app.sh`
  - `tools/hw/nh02/android-run-app-check.sh`
  - `tools/hw/nh02/android-run-app-check.sh --manual --wait-secs 130`
  - `tools/hw/nh02/android-run-app-check.sh --status --wait-secs 130`
  - `tools/hw/nh02/android-run-app-check.sh --sim --wait-secs 130`
  - `tools/hw/nh02/android-run-app-check.sh --sim-suite --wait-secs 1800`
  - `tools/hw/nh02/android-run-app-check.sh --anchor --wait-secs 130`
  - `tools/hw/nh02/android-run-app-check.sh --compass --wait-secs 130`
  - `tools/hw/nh02/android-run-app-check.sh --gps --wait-secs 180`
  - `tools/hw/nh02/android-run-app-check.sh --ota --ota-firmware boatlock/.pio/build/esp32s3/firmware.bin`
  - `tools/hw/nh02/android-run-app-check.sh --ota --ota-firmware boatlock/.pio/build/esp32s3/firmware.bin --wait-secs 1800`
  - `tools/hw/nh02/android-run-app-check.sh --reconnect --wait-secs 130`
  - `tools/hw/nh02/android-run-app-check.sh --esp-reset --wait-secs 130`
  - `tools/hw/nh02/android-install.sh`
  - `tools/hw/nh02/android-status.sh`
  - `tools/hw/nh02/android-wifi-debug.sh`
  - `tools/hw/nh02/android-run-smoke.sh`
  - `tools/hw/nh02/android-run-smoke.sh --manual --wait-secs 130`
  - `tools/hw/nh02/android-run-smoke.sh --status --wait-secs 130`
  - `tools/hw/nh02/android-run-smoke.sh --sim --wait-secs 130`
  - `tools/hw/nh02/android-run-smoke.sh --anchor --wait-secs 130`
  - `tools/hw/nh02/android-run-smoke.sh --compass --wait-secs 130`
  - `tools/hw/nh02/android-run-smoke.sh --gps --wait-secs 180`
  - `tools/hw/nh02/android-run-smoke.sh --reconnect --wait-secs 130`
  - `tools/hw/nh02/android-run-smoke.sh --esp-reset --wait-secs 130`
  - `tools/hw/nh02/android-run-smoke.sh --no-install`
  - `tools/hw/nh02/run-sim-suite.sh`
  - `tools/android/status.sh`
  - `tools/android/build-app-apk.sh`
  - `tools/android/run-smoke.sh`

## Working Rules

- Keep host-side ownership limited to `/opt/boatlock-hw` and the tracked RFC2217 service.
- Default refactor cadence runs hardware acceptance after every fifteenth module, not after every low-risk module.
- Run acceptance immediately when the module touches hardware drivers, pinout, deploy/debug wrappers, actuator safety, BLE reconnect/install behavior, or another path where local tests cannot bound the risk.
- When acceptance is due on the USB bench path, run it right after the seed/recovery flash so the boot path stays part of the same validation slice.
- Preserve the documented order for the chosen path. For normal moved hardware that means target proof, firmware build, phone BLE OTA, telemetry recovery, then Android BLE checks. For USB bench recovery that means `install -> flash -> acceptance -> monitor/debug`.
- Do not treat a missing ESP32 USB serial path as a blocker for the normal phone BLE OTA path when the Android phone target is proven and BLE OTA can run.
- For phones attached to `nh02`, use the tracked `android-install.sh` and `android-status.sh` path before falling back to local `adb` assumptions.
- Use `tools/hw/nh02/android-install-app.sh` when the task is only to install the normal production app APK on the `nh02` phone without running a smoke/check probe.
- For Wi-Fi ADB acceptance, seed it from the tracked USB-visible phone with `android-wifi-debug.sh`, then run the same smoke wrapper with `--serial <ip>:5555`; `adb devices` alone is not enough.
- Record whether failure is in first install policy, later `adb install -r` update, app launch, or BLE runtime; do not collapse those into one generic "Android smoke failed" verdict.
- Treat `android-run-smoke.sh --no-install` as BLE-runtime proof only; it does not prove that the exact just-built APK was installed on the phone.
- If full smoke fails with `INSTALL_FAILED_USER_RESTRICTED`, stop on that blocker. Required phone-side fixes are `Install via USB`, Xiaomi/MIUI security install confirmation, and any account or policy prompts that gate ADB installs.
- A logged first-attempt `INSTALL_FAILED_USER_RESTRICTED` followed by canonical retry `Success` and a passing `BOATLOCK_SMOKE_RESULT` is not a blocker; record the retry but trust the terminal wrapper verdict.
- Do not interrupt a live flash, build, acceptance run, or phone smoke while it is still making forward progress.
- If a bench or phone wrapper fails, fix that wrapper before normalizing a manual fallback.
- If a bench or phone wrapper returns stale, wrong, or ambiguous data, fix the wrapper or its guidance before trusting the result.
- For bash wrappers that run under macOS bash 3.2 with `set -u`, do not expand an empty array directly as `"${ARGS[@]}"`; branch on `${#ARGS[@]}` before expanding optional args.
- If `tools/hw/nh02/flash.sh --no-build` fails because expected PlatformIO artifacts are missing, rerun canonical `tools/hw/nh02/flash.sh` instead of hand-copying or reconstructing artifacts.
- Do not replace a pending or slow acceptance or phone-smoke verdict with manual `monitor.sh` or `logcat` interpretation. Use those only as blocker-debug context.
- Before live mutation on `nh02` or an attached Android phone, prove the exact target first and keep the recovery path explicit.
- Prefer repo-tracked scripts and remote helpers over ad-hoc inline `ssh` write commands or hand-typed mutation chains.
- For BLE OTA rollouts after live-frame schema changes, remember that the new
  APK is installed before the old firmware is updated. Keep enough app-side
  parser bridge for the installed firmware to emit first telemetry and start
  OTA, then prove the bridge with `tools/hw/nh02/deploy.sh`.
- If acceptance or monitor output disagrees with docs, update docs in the same change.
- Record every meaningful bench validation stage in `WORKLOG.md`.

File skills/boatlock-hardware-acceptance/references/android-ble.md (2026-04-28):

# Android USB + BLE Notes

## Current Local Capability

- `adb` is installed locally.
- Flutter and Android SDK are present locally.
- Current repo has Android app code under `boatlock_ui/android`.
- Current repo does not have a ready `integration_test/` BLE end-to-end suite.

## NH02 Bench Capability

- `nh02` can also act as the Android USB host, not only as the ESP32-S3 host.
- Current moved-hardware firmware updates normally use the phone as the BLE OTA
  bridge. USB ESP32 flashing is only the seed/recovery path unless the task
  explicitly targets USB bench flashing.
- Use `tools/hw/nh02/android-install.sh` to ensure `adb` exists on `nh02`.
- Use `tools/hw/nh02/android-status.sh` to check USB enumeration and `adb devices -l` on `nh02`.
- Use `tools/hw/nh02/android-wifi-debug.sh` after USB proof to switch the phone to ADB TCP/IP and print the Wi-Fi serial as `<ip>:5555`.
- Use `tools/hw/nh02/android-install-app.sh` to install the normal production app APK on the `nh02` phone without starting a smoke/check probe.
- Use `tools/hw/nh02/android-run-smoke.sh` to copy the ordinary release app APK to `nh02`, install or update it on the attached phone, launch a runtime check, and wait for `BOATLOCK_SMOKE_RESULT`.
- Pass `--serial <ip>:5555` to Android smoke/check wrappers when proving install/logcat/debug over Wi-Fi instead of USB.
- Use `tools/hw/nh02/android-run-smoke.sh --reconnect --wait-secs 130` to install/update the release app, wait for first telemetry, cycle phone Bluetooth through ADB, and require telemetry recovery without restarting the app.
- Use `tools/hw/nh02/android-run-smoke.sh --esp-reset --wait-secs 130` to install/update the release app, wait for first telemetry, reset the ESP32-S3 through the tracked reset helper, and require telemetry recovery without restarting the app.
- The operator firmware update paths are Android Settings -> `Файл на телефоне`
  and Settings -> `Последняя с GitHub`.
- Use `tools/hw/nh02/deploy.sh` only as bench automation for firmware+APK OTA proof. It builds the normal firmware and ordinary release APK, refreshes Android helpers only, installs the exact APK, serves firmware through `nh02` + `adb reverse`, starts the hidden runtime OTA check, uploads over BLE from the phone, and requires post-update telemetry recovery.
- Use `tools/hw/nh02/android-run-app-check.sh --ota --ota-firmware boatlock/.pio/build/esp32s3/firmware.bin` only as the lower-level OTA check when bypassing the build/deploy wrapper is intentional.
- Current BLE OTA requests high connection priority, a larger MTU, and write-without-response for chunks when Android and the characteristic support it; it falls back to acknowledged writes when required, so keep wrapper timeouts long enough for the slower path.
- On the Xiaomi test phone, BLE scan/OTA can fail silently when the screen is
  off. ADB `input keyevent` may be denied with `INJECT_EVENTS`, so the app
  Activity keeps itself visible with `showWhenLocked`, `turnScreenOn`, and
  `FLAG_KEEP_SCREEN_ON`.
- The app scan path must stay unfiltered at the Android scanner level. Apply
  BoatLock matching in Dart so name-only `BoatLock` adverts and `12ab` service
  adverts both work.
- If `nh02` shows the phone only as `MTP` or a vendor USB device and not in `adb devices`, the cable path is alive but USB debugging is still off on the phone.

## Install / Update Semantics Seen On The Xiaomi Test Phone

- Full acceptance requires the tracked wrapper to install the exact just-built APK with `adb install -r`; an already-installed app is not enough proof.
- Xiaomi/MIUI can block both first install and later update with `INSTALL_FAILED_USER_RESTRICTED`.
- Current Xiaomi bench phone has proven canonical ADB update only after the phone-side MIUI flow was satisfied: Xiaomi account, inserted SIM card, and `Install via USB` approval.
- Required phone-side fixes are `Install via USB`, any MIUI security install confirmation such as `USB debugging (Security settings)`, and any Xiaomi account, SIM-card, or policy prompt that gates ADB installs.
- If MIUI asks for `insert SIM card` after Xiaomi account login, treat it as a hard phone-side prerequisite for the canonical ADB install path. Do not patch around it in repo scripts.
- Use the wrapper's actual `adb install -r` result as the source of truth. `dumpsys user` may still print default restriction names and is blocker context, not a pass/fail verdict by itself.
- If a run returns `INSTALL_FAILED_USER_RESTRICTED` after this setup was previously proven, repeat the same exact install once while the phone is unlocked and the user can approve MIUI prompts.
- If the repeated exact install also fails, stop the acceptance path and fix the phone-side install policy. Do not continue with `--no-install`.
- `tools/hw/nh02/android-run-smoke.sh --no-install` exists for BLE-runtime debugging only. Do not use it as acceptance unless the user explicitly waives exact APK installation proof for that run.

## What Can Be Done Today

- Detect a USB-connected Android phone with `adb devices -l`.
- Detect a USB-connected Android phone on `nh02` with `tools/hw/nh02/android-status.sh`.
- Enable and verify ADB Wi-Fi on the same phone with `tools/hw/nh02/android-wifi-debug.sh`.
- Build the ordinary release app APK with `tools/android/build-app-apk.sh`.
- Install the normal production app APK on the `nh02` phone with `tools/hw/nh02/android-install-app.sh`.
- Install and run the smoke app with `tools/android/run-smoke.sh`.
- Use the phone as the real BLE central against the BoatLock bench.
- Prove BLE reconnect behavior on `nh02` with `tools/hw/nh02/android-run-smoke.sh --reconnect --wait-secs 130`.
- Prove recovery after ESP32 reboot on `nh02` with `tools/hw/nh02/android-run-smoke.sh --esp-reset --wait-secs 130`.
- Prove the bench phone-bridged BLE firmware update on `nh02` with `tools/hw/nh02/deploy.sh`.
- Read device logs with `adb logcat`.
- Update an already-installed release app APK over USB with `adb install -r` through the tracked wrapper.
- Drive assisted/manual smoke tests while watching:
  - phone logs
  - bench serial logs via `tools/hw/nh02/monitor.sh`
  - bench status via `tools/hw/nh02/status.sh`

## Current Smoke Scope

- The ordinary release app is built from `boatlock_ui/lib/main.dart`; smoke and acceptance checks are runtime modes inside that same app.
- It auto-starts BLE scan/connect on app launch.
- It passes only after receiving BoatLock telemetry with non-empty `mode` and `status`.
- It emits one structured log line prefixed with `BOATLOCK_SMOKE_RESULT ` for `adb` parsing.
- In reconnect mode, it first emits `BOATLOCK_SMOKE_STAGE {"stage":"first_telemetry"}`, waits for a telemetry gap caused by the wrapper's Bluetooth cycle, and passes only after telemetry returns.
- In ESP reset mode, the same reconnect APK is used, but the wrapper triggers the gap by resetting the ESP32-S3 instead of cycling phone Bluetooth.
- It is intentionally read-only and does not send `ANCHOR_ON`, manual, or other actuation commands.

## What Still Needs Extra Work For Full Automation

- Stable automation hooks for:
  - anchor-on deny/allow assertions
  - richer telemetry assertions

## Environment Limits Seen In This Session

- Local sandbox blocks starting the `adb` daemon without elevated execution.
- `flutter doctor` reports Android licenses are not fully accepted yet.

## Practical Next Step

- If a phone is connected with USB debugging enabled, first verify:
  - `tools/android/status.sh`
- If the phone is attached to `nh02` instead of the local workstation, first verify:
  - `tools/hw/nh02/android-install.sh`
  - `tools/hw/nh02/android-status.sh`
- Then run:
  - `tools/hw/nh02/android-run-smoke.sh`
- For reconnect acceptance, run:
  - `tools/hw/nh02/android-run-smoke.sh --reconnect --wait-secs 130`
- For ESP32 reboot recovery acceptance, run:
  - `tools/hw/nh02/android-run-smoke.sh --esp-reset --wait-secs 130`
- For phone-bridged BLE OTA flashing/acceptance, run:
  - `tools/hw/nh02/deploy.sh`
  - `tools/hw/nh02/deploy.sh --no-build` when both firmware and APK were already built
- After that, if stronger coverage is needed, add a narrow app-side flow for connect + heartbeat + anchor-on deny/allow checks.

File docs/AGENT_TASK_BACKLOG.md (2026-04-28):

# Agent Task Backlog

Status after the 2026-04-26 autonomous pass.

## Done In Main

- App-layer BLE command-wrapper legacy was removed from the release path;
  commands and OTA start requests are written directly through the ordinary app
  command path.
- Unknown BLE commands now fail the firmware command-profile gate in every
  profile.
- Product readiness docs were refreshed around current app, simulator, and
  hardware blockers.
- Flutter OTA can consume a validated release firmware manifest and exposes
  `Последняя с GitHub`.
- Android Settings exposes two operator firmware paths only: `Файл на телефоне`
  and `Последняя с GitHub`.
- CI now treats `release/**` branches as stabilization branches and publishes
  release artifacts only from `v*` tags through GitHub Releases.
- The app resolves the latest GitHub release as the firmware source, preferring a
  release manifest asset and falling back to unambiguous release assets
  with matching SHA-256 metadata.
- Flutter setup settings now roll back optimistic values when firmware
  accepts the BLE write but then rejects the command by profile in diagnostics.
- OTA upload failures in setup UI now show the rejected command, active
  profile, and required profile instead of a generic rejection.
- Smoke and production-app check result JSON now include structured
  `commandReject*` fields for firmware profile rejections.
- Offline Russian-water simulation now reports wave steepness, roll-rate, and
  GNSS/heading sensor-frame degradation metrics/events with thresholds for
  Rybinsk fetch and Ladoga storm scenarios.
- Android and macOS CI now publish one release app artifact per platform
  configured with the latest GitHub Release source; Android also supports
  phone-local firmware file selection.
- GitHub Releases now receive a release `firmware-esp32s3`
  asset set plus `manifest.json`, and the app can use token-backed release
  asset API URLs during validation.
- Android app check now has a manifest-backed latest-release OTA mode that serves
  `manifest.json` plus `firmware.bin` and uses the app firmware-update client
  before the normal BLE OTA/reconnect verdict.
- Manifest-backed Android OTA app check has been proven on `nh02` against the
  normal firmware profile, including phone HTTP manifest download, BLE upload,
  ESP32 reboot, and app telemetry recovery.
- The Flutter BLE client now binds all BoatLock GATT characteristics before
  enabling data/log notifications, treats the OTA characteristic as required
  for upload, and can clear the Android GATT cache plus rediscover when OTA is
  missing.
- OTA control commands now use the release app command path, and CI runs
  the setup UI widget test against the normal release app surface.
- Firmware OTA ownership is tied to the BLE connection handle that starts the
  update, so a non-owner central disconnect no longer aborts an active phone
  OTA transfer.
- macOS app acceptance now has a local wrapper that builds or unpacks the
  release artifact, validates the bundle/signature/entitlements, and can run a
  no-BLE launch smoke or manual update checklist.
- GitHub Pages was removed from the release path; release tags now produce
  unique flat GitHub Release asset names plus `manifest.json`.
- Offline simulator yaw inertia and explicit wake/chop events are implemented
  with thresholds and reports for core and Russian water scenarios.
- A pure firmware BLE control-owner lease policy helper is implemented and
  covered by native tests; live command-path wiring remains deferred.

## Active Background Work

- None. `Epicurus` left the GitHub latest-release source in the shared tree; it
  was reviewed, completed, and moved into main work.

## Next Autonomous Tasks

- Cut the next release from `release/v0.2.x` only after the release branch CI is
  green, then verify that `manifest.json` resolves
  `firmware-esp32s3.bin` from the published GitHub Release.
- Wire the pure multi-client control lease helper into the live BLE command path
  after per-client identity/source ownership is available.
- Decide whether Android/macOS app builds should intentionally replace the
  normal app or get distinct app/bundle IDs before operator distribution.

## Hardware-Gated Tasks

- Complete brushed motor driver intake before powered thruster tests:
  driver identity, pinout, safe idle, polarity, voltage/current limits,
  fault/current outputs, STOP/reset behavior.
- Complete steering driver intake before powered steering tests:
  actual driver type, steps-per-degree or gear ratio, travel limits, idle/hold
  current behavior, hard-stop/jam handling, and direction inversion.
- Do not change firmware motor/steering profiles for the real boat until those
  facts are captured. The current firmware assumes PWM plus two direction pins
  for the brushed motor and DRV8825-compatible STEP/DIR steering on the Vanchor
  `36:1` gearbox.
- After the next GitHub Release is published, prove the phone's
  `Последняя с GitHub` path against the public release manifest.

## Defer Or Move Out Of Main

- Route following, waypoint workflows, cruise/fishing convenience modes, and
  arrival-to-anchor flows.
- A second BLE controller or joystick until the control-owner lease model exists.
- Broad tuning/calibration UI in normal water builds; keep it setup-gated.
- Hardware-calibrated motor/steering simulation until powered bench logs exist.

## Agent Notes Captured

- `Darwin`: paired-mode hardening work is superseded by the KISS command-wrapper
  removal from the release protocol.
- `Carver` / `Russell`: app check and profile rejection gaps; implemented
  through fast-fail app check handling, settings rollback, detailed OTA rejections,
  and structured smoke/check result fields.
- `Helmholtz`: simulator wake/chop/sensor-frame implementation plan; wave
  steepness and sensor-frame degradation are implemented, wake bursts remain
  deferred until water-test inputs or powered logs exist.
- `Hubble`: motor and steering driver intake gates; hardware-gated.
- `Ohm`: keep-in-main vs defer plan; docs refreshed, unknown-command gate done,
  remaining multi-client and simulator work still open.
- `Jason`: one-button OTA should use durable release metadata, not raw expiring
  Actions artifacts; implemented through app manifest client and GitHub Release
  assets.
- `Epicurus`: latest GitHub release source; implemented through release parsing,
  release artifacts, release manifest publishing, and token-backed asset API
  support in the app release client.
- `Bacon`: OTA commands must be written through the release app command
  path; implemented and covered.
- `Leibniz`: one-button release OTA mostly existed, but setup UI CI, stale
  OTA throughput docs, and real release/macOS proof gaps were identified. CI/docs
  fixes are implemented; release/macOS proof remains open.
- `Hume`: Android OTA failure triage pointed at missing OTA characteristic
  detail, release artifact consistency, and stale remote-helper risks.
  The OTA diagnostics/artifact guidance was fixed and `install.sh` was rerun
  before hardware proof.
- `Faraday`: prioritized the remaining autonomous/gated tasks; `nh02`
  manifest-backed OTA and release return-to-bench proof are now complete, while
  powered hardware intake and control-owner lease remain open.

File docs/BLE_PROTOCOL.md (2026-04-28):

# BLE Protocol

BoatLock uses one custom GATT service for the app and bench tooling:

- Service UUID `12ab`
- Live state characteristic `34cd`: notify/read, compact binary v5 frame
- Control point characteristic `56ef`: write/write-no-response, printable ASCII commands
- Device log characteristic `78ab`: notify, text log lines
- Firmware OTA characteristic `9abc`: binary writes accepted only after `OTA_BEGIN`

The live path is not a serial/JSON tunnel. The app subscribes to `34cd`, sends
`STREAM_START`, and receives fixed-size binary live frames. Large snapshots and
parameter reads are not part of the protocol.

## Control Point Commands

Control point payloads are application-level command byte strings, not a text
stream. Valid command writes are `1..191` printable ASCII bytes
(`0x20..0x7E`). Clients reject empty, overlong, control-byte, embedded-NUL, and
non-ASCII commands before writing `56ef`; firmware rejects the same malformed
payloads before queueing.

There is no BoatLock BLE command wrapper in the release protocol. The app writes
the command listed below directly to `56ef`; firmware safety gates remain
authoritative for motion, Anchor enable, Manual deadman, OTA integrity, and
profile command scope.

Current classification:

- `release`: `STREAM_START`, `STREAM_STOP`, `SNAPSHOT`, `SET_ANCHOR`,
  `ANCHOR_ON`, `ANCHOR_OFF`, `STOP`, `HEARTBEAT`, `MANUAL_TARGET`,
  `MANUAL_OFF`, `NUDGE_DIR`, `NUDGE_BRG`, `SET_HOLD_HEADING`,
  `SET_ANCHOR_PROFILE`, `SET_COMPASS_OFFSET`, `RESET_COMPASS_OFFSET`,
  `COMPASS_CAL_START`, `COMPASS_DCD_SAVE`, `COMPASS_DCD_AUTOSAVE_ON`,
  `COMPASS_DCD_AUTOSAVE_OFF`, `COMPASS_TARE_Z`, `COMPASS_TARE_SAVE`,
  `COMPASS_TARE_CLEAR`, `SET_STEP_MAXSPD`, `SET_STEP_ACCEL`, `SET_STEP_SPR`,
  `SET_STEP_GEAR`, `SET_STEPPER_BOW`, `OTA_BEGIN`, `OTA_FINISH`, `OTA_ABORT`,
  `SIM_LIST`, `SIM_RUN`, `SIM_STATUS`, `SIM_REPORT`, `SIM_ABORT`.
- `dev/HIL`: `SET_PHONE_GPS`.

| Command | Parameters | Description |
|---|---|---|
| `STREAM_START` | none | Enable periodic live-state notifications and emit one live frame |
| `STREAM_STOP` | none | Disable periodic live-state notifications and clear queued live frames |
| `SNAPSHOT` | none | Emit one live-state frame without changing stream state |
| `SET_ANCHOR:<lat>,<lon>` | valid non-zero decimal degrees | Save anchor position with current heading; does not enable Anchor mode |
| `ANCHOR_ON` | none | Enable Anchor only with a saved point, onboard heading, and sufficient GNSS quality |
| `ANCHOR_OFF` | none | Disable Anchor immediately, stop actuation, and clear latched `HOLD` state |
| `STOP` | none | Emergency stop: disable Anchor/Manual, stop all motors, and latch `HOLD` |
| `HEARTBEAT` | none | Keep-alive from the app; missing heartbeat while Anchor is active triggers failsafe |
| `MANUAL_TARGET:<angleDeg>,<throttlePct>,<ttlMs>` | `angleDeg=-90..90`, `throttlePct=-100..100`, `ttlMs=100..1000` | Atomically enter/refresh Manual; disables Anchor and acts as a deadman lease |
| `MANUAL_OFF` | none | Stop Manual mode and zero manual outputs |
| `NUDGE_DIR:<FWD\|BACK\|LEFT\|RIGHT>` | direction | Shift anchor point by the fixed jog step while Anchor is active and safety checks pass |
| `NUDGE_BRG:<bearingDeg>` | absolute bearing | Shift anchor point by the fixed jog step on a bearing while Anchor is active |
| `SET_ANCHOR_PROFILE:<quiet\|normal\|current>` | profile id | Apply and persist Anchor preset values |
| `SET_HOLD_HEADING:<0|1>` | integer flag | Enable or disable heading hold |
| `SET_PHONE_GPS:<lat>,<lon>[,<speedKmh>[,<satellites>]]` | external fix | Dev/HIL injection only; normal app control does not use phone GPS for anchor control |
| `SET_COMPASS_OFFSET:<deg>` | float degrees | Set persistent BNO08x heading offset |
| `RESET_COMPASS_OFFSET` | none | Reset persistent BNO08x heading offset to `0` |
| `COMPASS_CAL_START` | none | SH2-UART build only: enable BNO08x dynamic calibration |
| `COMPASS_DCD_SAVE` | none | SH2-UART build only: request BNO08x DCD save |
| `COMPASS_DCD_AUTOSAVE_ON` | none | SH2-UART build only: enable BNO08x automatic DCD save |
| `COMPASS_DCD_AUTOSAVE_OFF` | none | SH2-UART build only: disable BNO08x automatic DCD save |
| `COMPASS_TARE_Z` | none | SH2-UART build only: tare Z/heading basis |
| `COMPASS_TARE_SAVE` | none | SH2-UART build only: persist last tare |
| `COMPASS_TARE_CLEAR` | none | SH2-UART build only: clear persisted tare |
| `SET_STEP_MAXSPD:<float>` | steps/s | Maximum stepper speed |
| `SET_STEP_ACCEL:<float>` | steps/s² | Stepper acceleration |
| `SET_STEP_SPR:<int>` | steps/rev | Motor STEP pulses per motor revolution |
| `SET_STEP_GEAR:<float>` | ratio | Mechanical reduction from stepper motor to steering output shaft |
| `SET_STEPPER_BOW` | none | Save current stepper position as boat-bow zero |
| `OTA_BEGIN:<size>,<sha256>` | bytes + 64-hex SHA-256 | Stop outputs, arm inactive OTA partition, and accept binary chunks on `9abc` |
| `OTA_FINISH` | none | Validate byte count and SHA-256, finalize OTA image, then reboot |
| `OTA_ABORT` | none | Abort active BLE OTA and keep current firmware |
| `SIM_LIST` | none | List built-in HIL scenarios |
| `SIM_RUN:<scenario_id>[,<speedup>]` | id + speed mode | Start deterministic on-device simulation |
| `SIM_STATUS` | none | Return simulation progress JSON |
| `SIM_REPORT` | none | Return final simulation report JSON in logs |
| `SIM_ABORT` | none | Abort currently running simulation |

`SIM_*` is release-scope because simulation is a quiet software mode inside the
ordinary firmware. Real sensor values are ignored for control/display while the
scenario is active, actuator outputs are quieted, and live BLE telemetry carries
the simulated boat position/heading. `SET_PHONE_GPS` remains dev/HIL only.

Manual control is intentionally a single atomic command instead of separate
mode/direction/speed writes. Each accepted `MANUAL_TARGET` refreshes the
deadman TTL for the current controller source. If updates stop, firmware exits
Manual mode and stops output.

## Control Ownership

The current release path has one normal product controller: the phone app.
Multiple telemetry subscribers may be allowed by BLE transport, but a second
actuating controller must not be treated as implemented until it has explicit
controller identity, a single-owner lease, role allowlists, and bench tests.

The existing lease helper models that future work for Manual/Anchor ownership:
read-only transport commands do not acquire ownership, eligible app control
commands acquire/refresh a lease, non-owner control is busy until the lease
expires, and `STOP` preempts. It does not use a BLE command-wrapper/session
layer.

## Firmware Scope Gate

Firmware builds enforce the command scope selected by the PlatformIO profile.
The default `esp32s3` environment is the normal release firmware and includes
BLE OTA plus hardware setup commands. `esp32s3_acceptance` additionally accepts
dev/HIL sensor injection.

Gate behavior expectations:

- Unknown commands and disallowed profile commands fail closed before settings,
  modes, OTA, simulation, injected GNSS, motor, or stepper state can change.
- Rejections are logged as `[BLE] command rejected reason=profile ...`.
- `OTA_BEGIN`, `OTA_FINISH`, and `OTA_ABORT` are release commands. The normal
  firmware must remain OTA-capable so moved hardware can be updated through the
  phone BLE path.
- During active OTA, firmware rejects runtime commands except `HEARTBEAT`,
  `OTA_FINISH`, and `OTA_ABORT`.

## BLE Firmware OTA

BLE OTA uses the phone as the bridge:

1. The app either reads a phone-local `firmware.bin` and computes SHA-256, or
   downloads the latest GitHub Release firmware and verifies it against the
   release manifest SHA-256.
2. The app sends `OTA_BEGIN:<size>,<sha256>` over `56ef`.
3. Firmware disables Anchor, stops Manual and all outputs, latches `HOLD`, and
   logs `[OTA] begin ok ...`.
4. The Android app requests high connection priority and larger MTU, then writes
   firmware bytes to `9abc` in chunks up to `MTU - 3`.
5. The app sends `OTA_FINISH`; firmware checks received byte count and SHA-256.
6. On success firmware logs `[OTA] finish ok ...`, waits briefly, and restarts.

Chunk writes before a successful `OTA_BEGIN` are ignored. If the BLE link
disconnects during an active transfer, firmware aborts the update and keeps the
current boot partition.

The release app uses the latest GitHub Release for one-button updates. A release
should include `manifest.json` plus `firmware-esp32s3.bin`; the manifest must
describe a `release/vX.Y.x` branch `esp32s3` binary with
`commandProfile=release`, positive size, HTTPS binary URL, and a 64-hex
SHA-256.

## Live State Frame

`34cd` notifications carry exactly one 65-byte little-endian binary frame.
Receivers reject shorter or longer payloads, wrong magic/version/type, and
unknown enum codes.

- bytes `0..1`: magic `BL`
- byte `2`: protocol version, currently `5`
- byte `3`: frame type, `1` for live telemetry
- bytes `4..5`: sequence `uint16`
- bytes `6..7`: flags `uint16`
- byte `8`: mode code (`0=IDLE`, `1=HOLD`, `2=ANCHOR`, `3=MANUAL`, `4=SIM`)
- byte `9`: status code (`0=OK`, `1=WARN`, `2=ALERT`)
- bytes `10..25`: `lat`, `lon`, `anchorLat`, `anchorLon` as signed `deg * 1e7`
- bytes `26..33`: `anchorHead`, `distance`, `anchorBearing`, `heading`
- byte `34`: battery percent
- bytes `35..42`: `stepSpr`, `stepGear*10`, `stepMaxSpd`, `stepAccel`
- bytes `43..59`: compass heading/raw/offset/quality/motion fields
- bytes `60..63`: status reason bitmask
- byte `64`: GNSS quality (`0` none, `1` weak, `2` good)

Flag bits:

- bit `0`: `holdHeading`

Reason flags are decoded by the Flutter app into `statusReasons` strings such as
`NO_GPS`, `NO_COMPASS`, `DRIFT_FAIL`, `CONTAINMENT_BREACH`, `COMM_TIMEOUT`, and
GNSS gate reasons like `GPS_DATA_STALE`, `GPS_HDOP_MISSING`, and
`GPS_POSITION_JUMP`.

Firmware `mode` is currently one of `IDLE`, `HOLD`, `ANCHOR`, `MANUAL`, `SIM`.
Telemetry outside the live frame should be added as an explicit new frame type
or event, not as ad-hoc JSON on the live characteristic.

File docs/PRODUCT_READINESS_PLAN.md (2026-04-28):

# BoatLock Product Readiness Plan

Date: 2026-04-26

This plan prepares BoatLock for powered bench tests and first protected-water
tests after the repo-wide refactor. Code remains the source of truth; this file
records the product and validation backlog that should drive the next cuts.

## Product Goal

`main` should stay focused on the releasable BoatLock path:

- app connection/reconnection over BLE
- set anchor, enable anchor, disable anchor, emergency stop
- deadman-protected manual control from phone and future BLE remote
- anchor hold from hardware GNSS plus onboard BNO08x heading
- deterministic failsafe behavior with no unexpected actuation
- enough status to understand link, fix, heading, anchor, safety, and actuation

Do not restore route navigation, phone-heading fallback, legacy split manual
commands, or compatibility shims unless a later task explicitly restores them
end to end.

## Commercial Baseline

Current commercial GPS-anchor products set the user expectation:

- Minn Kota Spot-Lock exposes lock/unlock from multiple control surfaces,
  small-step 5 ft jog, and distance-to-spot telemetry:
  <https://minnkota.johnsonoutdoors.com/us/learn/technology/spot-lock>
- Minn Kota One-Boat Network app puts speed, steering, Spot-Lock, AutoPilot,
  Drift Mode, and update/support flows in one app:
  <https://minnkota.johnsonoutdoors.com/us/learn/technology/one-boat-network-app>
- Minn Kota Advanced GPS docs treat heading sensor calibration/offset and
  boat-scale tuning as setup requirements, not hidden debug details:
  <https://minnkota-help.johnsonoutdoors.com/hc/en-us/articles/23607178243991-Using-Advanced-GPS-Navigation-Features-and-Manual-2023-present>
  and
  <https://minnkota-help.johnsonoutdoors.com/hc/en-us/articles/31296915731735-Using-the-Advanced-GPS-Navigation-Micro-Remote>
- Garmin Force separates manual, heading hold, anchor lock, and jog behavior on
  the remote:
  <https://www8.garmin.com/manuals/webhelp/GUID-91136105-7EB2-442E-8C25-7B4CF00FC466/EN-US/GUID-86396A06-E8A7-4E7B-97F5-A638D9DBAB49.html>
- Lowrance Ghost gives physical feedback for Anchor/Heading modes and exposes
  battery, pairing, and mode state at a glance:
  <https://www.lowrance.com/lowrance/type/trolling-motor/ghost-47/>
- MotorGuide Pinpoint GPS includes anchor, jog, heading lock, cruise control,
  wireless foot/hand remote, and chartplotter integration:
  <https://shop.motorguide.com/products/940800280.html>
- Rhodan/Raymarine integration exposes Anchor Here, Hold Heading, speed/thrust
  control, 5 ft increments, and wind/current compensation:
  <https://www.raymarine.com/en-us/learning/online-guides/rhodan-trolling-motor-integration>
- Minn Kota sizing guidance says thrust must be sized by loaded boat weight and
  increased for wind/current:
  <https://minnkota.johnsonoutdoors.com/us/learn/buying-guide/trolling-motors>

BoatLock should not copy the full fishing-feature matrix. The useful baseline is
the interaction model: explicit modes, visible readiness, small jog, separate
setup/calibration, conservative power sizing, and clear errors.
The focused comparison is tracked in `docs/COMMERCIAL_ANCHOR_UX_REVIEW.md`.

## Current Fit

What matches the target:

- Firmware orchestration is now mostly glue in `boatlock/main.cpp`, with mode
  arbitration, GNSS, motion, telemetry cadence, anchor gate, sim execution, and
  status split into narrower modules.
- BLE protocol uses fixed UUIDs, fixed-size live telemetry, command validation,
  logs, and OTA partition safety.
- Manual control uses atomic `MANUAL_TARGET:<angleDeg>,<throttlePct>,<ttlMs>` and
  `MANUAL_OFF`, with a short deadman TTL and source-owned lease.
- Multi-client control ownership is now specified as a future implementation
  contract: read-only telemetry clients may coexist, but only one eligible
  controller can hold the control lease.
- `ANCHOR_ON` is behind anchor-point, heading, and GNSS quality gates.
- STOP/failsafes latch quiet `HOLD` instead of auto-entering manual control.
- On-device HIL `S0..S19` plus `RF0..RF4` and offline `tools/sim` are real validation assets and
  should stay in `main`.
- Native production-path tests now cover the shared
  `RuntimeMotion -> StepperControl -> MotorControl` quiet-output cases for STOP,
  Manual-to-HOLD, Anchor-to-HOLD, and DriftFail.

Important mismatch:

- On-device HIL exercises `AnchorControlLoop` through virtual sensor/actuator
  interfaces, while production actuation goes through the real runtime motion and
  driver classes. HIL pass is useful, but it does not prove powered steering
  direction, torque/current limits, end stops, or water-loaded motor behavior.

## Priority Gaps

### P0 Before Powered Bench

- Keep app command acceptance explicit: operator UI must distinguish command
  sent from telemetry/log-confirmed acceptance, especially for setup and
  acceptance workflows.
- Prove app-visible firmware command-profile rejections on `nh02` and Android so
  release firmware blocking setup/dev/HIL commands cannot look like a silent
  write.
- Prove or fix GPS-to-compass correction source ownership. Phone GPS fallback is
  display/telemetry only and must not indirectly bias control heading correction.
- Prove BLE command profiles end-to-end on `nh02` and Android: release rejection
  logs, setup positive paths, and acceptance HIL positive paths.
- Identify the exact brushed/collector motor driver with
  `docs/BRUSHED_MOTOR_DRIVER_INTAKE.md`. Current firmware only proves a simple
  `PWM=7` plus `DIR=8/10` command shape; it does not prove the real driver's
  brake/coast, enable, fault, current-limit, thermal, polarity, or safe-idle
  behavior.
- Finish the steering stepper driver and mechanics capture. Current firmware is
  fixed to a DRV8825-compatible STEP/DIR path on `STEP=GPIO6`, `DIR=GPIO16`.
  Geometry uses `StepSpr=200` motor STEP pulses/rev and `StepGear=36` from the
  Vanchor gearbox, producing `7200` output-shaft STEP pulses/rev. Use
  `docs/STEERING_DRIVER_INTAKE.md` to capture
  torque/current limits, enable/sleep/reset wiring, stop behavior, and tests.
- Build a powered-bench acceptance procedure for `PWM=7`, `DIR=8/10`, the actual
  brushed motor driver, and the actual steering drive. Before connecting the
  prop/motor load, prove boot/STOP/HOLD/reconnect/anchor-denial keep outputs at
  safe idle.
- Add current-limited power, fuse/breaker, physical kill path, cable strain relief,
  and polarity proof before any real motor spin.
- Update wiring docs every time hardware truth changes; do not rely on stale
  README snippets.

### P1 Before First Water

- Turn the protected-water checklist into app-driven readiness where practical:
  live-frame age, RSSI, GNSS/heading freshness, active firmware
  profile, STOP proof, manual-release proof, and active blockers.
- Keep current anchor controls covered by tests: current-position save,
  map-point save, enable/disable, fixed 1.5 m jog, distance/bearing, and blocked
  reasons.
- Add conservative anchor profiles for water trials: `quiet`, `normal`, `current`,
  with `quiet` as the default for first powered tests.
- Add export/screenshot bundle for water-test sessions after the event shape is
  stable.
- Add battery/power telemetry later; for the first powered bench and protected
  water sessions, `docs/PROTECTED_WATER_TEST_LOG.md` is the required external
  voltage/current/power measurement path. Motor sizing and runtime are not
  product polish; they directly bound safety.
- Remove current main-branch leftovers that confuse release scope: old route UI
  labels, unused persisted knobs such as `ReacqStrat`, and board-specific
  `BOATLOCK_BOARD_JC4832W535` branches unless they are explicitly preserved on a
  feature branch.

### P2 Product Polish After Safe Water Proof

- Add heading-hold as a separate operator concept from position hold in the app.
- Add setup flows for heading offset, steering bow-zero, and boat
  scale style tuning.
- Implement the documented second-controller gate in `docs/MANUAL_CONTROL.md`
  and `docs/BLE_PROTOCOL.md`: per-client identity, read-only telemetry
  clients, single control-owner lease, conservative takeover, remote role
  allowlist, STOP preemption, and two-central tests before accepting a real BLE
  remote.
- Optimize BLE OTA throughput only after the powered path is stable; keep SHA-256,
  abort-on-disconnect, and USB flash recovery.

## Simulation Plan

Keep two layers:

- Offline Python sim for fast environmental sweeps and research-backed scenario
  generation.
- On-device HIL for release-firmware `SIM_*` acceptance, simulated BLE map telemetry, and BLE/app smoke.

Next simulation work:

- Keep schema v2 Russian scenarios with provenance/confidence, loaded mass,
  submerged drag, and windage as the current baseline.
- Improve provenance granularity and confidence calibration only after real
  bench/water logs exist.
- Add yaw moment and heading inertia so current, wind/gust, and wave forcing can
  rotate the hull, not only translate it.
- Add river/reservoir wake events and short steep chop as separate transient
  disturbances instead of folding them into steady wave height.
- Extend current wave/rocking support from hull-motion metrics to sensor-frame
  effects on BNO08x/GNSS samples: roll, pitch, heave, heading jitter, and
  measurement quality changes.
- Extend reports and thresholds for pitch, heave, heading jitter, degraded GNSS
  time, wake/chop active time, and environmental yaw rate.
- Keep motor and steering hardware-calibration simulation work blocked on real
  driver identity and logs.

## Bench Plan

1. Local validation:
   `tools/ci/run_local_prepowered_gate.sh`, or the equivalent manual sequence:
   `cd boatlock && platformio test -e native`,
   `cd boatlock && pio run -e esp32s3`,
   `python3 tools/sim/test_sim_core.py`,
   `python3 tools/sim/run_sim.py --check --json-out tools/sim/report.json`,
   `python3 tools/sim/test_soak.py`,
   `python3 tools/sim/run_soak.py --hours 6 --check --json-out tools/sim/soak_report.json`,
   `cd boatlock_ui && flutter test`,
   `pytest tools/ci/test_*.py`.
2. NH02 no-load gate:
   `tools/hw/nh02/flash.sh`,
   `tools/hw/nh02/acceptance.sh --seconds 180`,
   Android `--status`, `--sim`, `--anchor`, `--manual`, `--reconnect`,
   `--esp-reset`, plus GPS smoke when hardware GPS is visible.
3. Output-instrumented gate:
   motor physically disconnected, logic analyzer or meter on `PWM=7`, `DIR=8/10`,
   steering driver outputs observed, prove idle on boot, STOP, HOLD, reconnect,
   anchor denial, SIM start/abort, and OTA begin.
4. Low-power powered gate:
   complete `docs/STEERING_DRIVER_INTAKE.md` for the current DRV8825 steering
   path, then use current-limited supply,
   fuse/breaker, prop removed or safe test load, real driver connected, short
   manual pulses, direction proof, STOP proof, thermal check, no auto anchor.
5. Integrated dry steering gate:
   steering motor attached to the turn mechanism without thrust load, bow-zero
   captured, manual left/right, auto point-to-bearing with compass rotation,
   release/idle behavior, jam/limit observation.
6. Wet/tank/tether gate:
   motor submerged or safe water load, very low thrust cap, manual-only first,
   then anchor enable denial/proof, then short anchor holds.

## First Water Plan

Start only in protected small lake/cove conditions: low wind, minimal current,
two operators, physical recovery available, and a hard way to remove power.
Use `docs/PROTECTED_WATER_TEST_LOG.md` as the session checklist and do not
advance phases after any abort condition.

Phases:

1. Float and telemetry only: no powered output. Verify BLE, GNSS, heading,
   readiness panel, logs, display, and STOP.
2. Manual low-power: short target-angle/PWM windows, TTL expiry, BLE loss,
   phone lock/app background, hardware STOP, reconnect.
3. Steering-only: motor thrust disabled, verify stepper/steering direction,
   bow-zero, release, and no hunting.
4. Anchor preflight denied/accepted: verify denied reasons first, then accepted
   only with `gnssQ=2`, fresh heading, and saved anchor.
5. Short anchor hold with quiet profile: 30-60 seconds, low thrust cap,
   containment close, manual STOP recovery.
6. Longer hold: 5-10 minutes, observe drift track, PWM, heading error, stepper
   movement, battery/current, and no repeated twitching.
7. Controlled disturbances: small wind/current changes, wakes if safe, then
   explicit abort. Do not test flood/current/storm classes until containment and
   powered bench logs are clean.

Abort immediately on unexpected actuation, stale UI control enabled after link
loss, missing STOP effect, compass loss, GNSS jump, repeated steering thrash,
unbounded PWM saturation, water ingress, overheated wiring/driver, or uncertain
operator state.

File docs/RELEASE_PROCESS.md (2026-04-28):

# BoatLock Release Process

BoatLock releases are cut from stabilization branches and delivered through
GitHub Releases. GitHub Pages is not a firmware-update channel.

## Branches

- `main` is the integration branch.
- `release/vX.Y.x` is the stabilization branch for a patch series.
- Tags use `vX.Y.Z` and must be created from a commit contained in the matching
  `release/vX.Y.x` branch.

Example:

```bash
git checkout main
git pull --ff-only
git checkout -b release/v0.2.x
git push -u origin release/v0.2.x
```

## Release Gate

Before tagging:

```bash
python3 tools/ci/check_firmware_version.py
python3 tools/ci/check_config_schema_version.py
pytest tools/ci/test_*.py
cd boatlock && platformio test -e native
cd ../boatlock_ui && flutter test
```

For hardware-bearing changes, also run the `nh02` and Android acceptance
wrappers documented in `docs/HARDWARE_NH02.md`.

## Tagging

On the release branch, bump `kFirmwareVersion`, `CHANGELOG.md`, and
`docs/releases/<version>.md` together. Then tag and push:

```bash
git checkout release/v0.2.x
git pull --ff-only
python3 tools/ci/check_firmware_version.py --tag v0.2.1
python3 tools/ci/check_release_ref.py --tag v0.2.1 --require-current-commit
git tag v0.2.1
git push origin release/v0.2.x v0.2.1
```

CI publishes the GitHub Release from `v*` tags only.

## Release Assets

The release job flattens CI artifacts into unique GitHub Release asset names:

- `manifest.json`
- `firmware-esp32s3.bin`
- `bootloader-esp32s3.bin`
- `partitions-esp32s3.bin`
- `firmware-esp32s3.elf`
- `BUILD_INFO-esp32s3.txt`
- `SHA256SUMS-esp32s3.txt`
- Android/macOS/web app artifacts and simulation reports

The release app reads `manifest.json` from the latest GitHub Release for
`dslimp/boatlock`. The manifest points at `firmware-esp32s3.bin` and must use
`channel=release`, `branch=release/vX.Y.x`, `platformioEnv=esp32s3`, and
`commandProfile=release`.

## Android App Signing

Tagged Android release APKs must be signed with the same long-lived release
certificate for the lifetime of the app. Android accepts an APK update only when
the new APK certificate matches the installed app certificate, so GitHub Release
APKs must not use the runner's generated debug keystore.

Keep the private keystore outside the repository and configure these GitHub
Secrets before pushing a `v*` tag:

- `BOATLOCK_ANDROID_KEYSTORE_BASE64`
- `BOATLOCK_ANDROID_KEYSTORE_PASSWORD`
- `BOATLOCK_ANDROID_KEY_ALIAS`
- `BOATLOCK_ANDROID_KEY_PASSWORD`

Example secret setup from a local private keystore:

```bash
mkdir -p ~/.boatlock
keytool -genkeypair \
  -v \
  -keystore ~/.boatlock/boatlock-release.jks \
  -storetype JKS \
  -keyalg RSA \
  -keysize 4096 \
  -validity 10000 \
  -alias boatlock-release
base64 < ~/.boatlock/boatlock-release.jks | gh secret set BOATLOCK_ANDROID_KEYSTORE_BASE64
gh secret set BOATLOCK_ANDROID_KEYSTORE_PASSWORD
gh secret set BOATLOCK_ANDROID_KEY_ALIAS
gh secret set BOATLOCK_ANDROID_KEY_PASSWORD
```

Branch and pull-request Android builds may fall back to debug signing for CI
coverage. A tagged `v*` build fails if release signing secrets are missing.

## Local App Builds

```bash
tools/android/build-app-apk.sh
tools/macos/build-app.sh
tools/macos/acceptance.sh --static-only
```

For `nh02` proof of the same public latest-release path used by the phone
button:

```bash
tools/hw/nh02/android-run-app-check.sh \
  --ota-latest-release \
  --wait-secs 1800
```

For bench-only validation of an unpublished local firmware through a temporary
served manifest:

```bash
tools/hw/nh02/android-run-app-check.sh \
  --ota-latest-release \
  --ota-firmware boatlock/.pio/build/esp32s3/firmware.bin \
  --wait-secs 1800
```

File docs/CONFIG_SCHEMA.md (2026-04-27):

# Config Schema

Schema version: `0x1D` (`Settings::VERSION`).

Settings are stored in ESP32 NVS namespace `boatlock_cfg` as:

1. `schema` (`uint8_t`)
2. one raw `float` blob per setting key

On boot:

- missing keys keep current defaults and are persisted on the next boot writeback
- removed keys are ignored
- older schema versions keep existing values by current key, apply explicit migration rules, and write the current schema marker
- future schema versions are loaded read-only: current known keys may be used in RAM, but boot does not downgrade the `schema` marker or write missing/default keys
- invalid NVS values use defaults and are persisted on the next boot writeback
- any loaded value outside allowed range is normalized and logged as `CONFIG_REJECTED`

Write policy:

- runtime `save()` writes NVS only when settings are dirty
- dirty setting keys are staged and committed with one `nvs_commit()`
- setting a value equal to the current normalized value does not create a flash commit
- non-finite runtime values are rejected instead of being persisted
- failed NVS set/commit calls are logged as `CONFIG_SAVE_FAILED` and keep settings dirty for retry
- older-version migration, missing-key recovery, and boot-time normalization still force a commit
- future-version rollback does not force a boot commit; operator-initiated setting changes can still be saved by the older firmware

Migration rules:

- versioned migrations live in `Settings::applyMigrations()`
- key renames must be encoded as explicit legacy-key rules instead of relying on defaults
- current legacy rule: schemas before `0x18` may migrate legacy `MaxThrust` into `MaxThrustA` when `MaxThrustA` is missing
- schemas before `0x1A` migrate the exact untouched anchor default bundle
  `HoldRadius=2.5`, `DeadbandM=1.5`, `MaxThrustA=60`, `ThrRampA=35`
  to quiet defaults `3.0/2.2/45/20`; any custom/profile value preserves the stored bundle
- schemas before `0x1C` migrate the exact untouched stepper default pair
  `StepMaxSpd=700`, `StepAccel=250` to the DRV8825/Vanchor defaults
  `1200/800`; any custom value preserves the stored pair
- schemas before `0x1D` split legacy output-shaft `StepSpr` into
  motor-side `StepSpr` and `StepGear=36`; for example `7200` becomes
  `StepSpr=200`, `StepGear=36`
- schemas before `0x1D` migrate the exact untouched DRV8825/Vanchor
  stepper speed pair `StepMaxSpd=1200`, `StepAccel=800` to `2400/2400`;
  any custom value preserves the stored pair

## Groups

### GNSS quality gate

- `MinFixType` (`2..3`)
- `MinSats` (`3..20`)
- `MaxHdop` (`0.5..10`)
- `MaxGpsAgeMs` (`300..20000`)
- `MaxPosJumpM` (`1..200`)
- `MinStatSpd` (`0.05..2.0`)
- `SpdSanity` (`0..1`)
- `MaxSpdMps` (`1..60`)
- `MaxAccMps2` (`0.5..20`)
- `ReqSent` (`0..20`)

`MinFixType` is reserved in current runtime build.

- active runtime source: `fix_type_source = NONE`
- runtime value: `fix_type = UNKNOWN`
- one-shot boot event:
  `CONFIG_FIELD_IGNORED field=min_fix_type reason=fix_type_unavailable`

### Anchor control

- `HoldRadius` (`0.5..20`)
- `DeadbandM` (`0.2..10`)
- `MaxThrustA` (`10..100`)
- `ThrRampA` (`1..100`)
- `MaxTurnRt` (`30..720`)

Legacy runtime PID knobs are removed. Anchor thrust uses bounded deadband, max-thrust, approach damping, anti-hunt timing, and slew/ramp limiting instead of hidden self-adaptive PID persistence.

### Safety supervisor

- `CommToutMs` (`3000..60000`)
- `CtrlLoopMs` (`100..10000`)
- `SensorTout` (`300..30000`)

Runtime failsafes always stop motion and latch `HOLD`. They do not automatically enter `MANUAL`; operator control must be re-enabled explicitly after a failsafe.

### UX / Events

- `DriftAlert` (`2..200`)
- `DriftFail` (`5..500`)
- `GpsWeakHys` (`0.5..60`)
- `EventRateMs` (`100..10000`)

### Steering

- `StepMaxSpd` (`100..4000`)
- `StepAccel` (`50..4000`)
- `StepSpr` (`50..6400`)
- `StepGear` (`1..100`)

Current steering geometry default is `200` motor STEP pulses per motor
revolution and `StepGear=36`, for `7200` output-shaft STEP pulses per
revolution. With DRV8825 MODE pins left disconnected, the driver is in
full-step mode, so a normal `1.8°` motor uses `200` pulses/rev. If
microstepping is wired later, set `StepSpr` to motor pulses/rev after the
microstep multiplier, and keep `StepGear` as the mechanical reduction ratio.
Default steering tuning is `StepMaxSpd=2400` motor steps/s and
`StepAccel=2400` motor steps/s2.

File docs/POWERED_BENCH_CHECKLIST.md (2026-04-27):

# BoatLock Powered Bench Checklist

This checklist is the required gate before connecting the brushed motor,
steering motor, prop load, or water load. It complements `docs/HARDWARE_NH02.md`;
use the tracked wrappers there for flash, acceptance, and Android BLE smokes.

## Current Known Outputs

Firmware source of truth is `boatlock/main.cpp`.

- Brushed motor PWM: `GPIO7`
- Brushed motor direction: `GPIO8` and `GPIO10`
- Current steering firmware path: DRV8825-compatible `STEP/DIR` through
  AccelStepper `DRIVER` pins `STEP=GPIO6`, `DIR=GPIO16`
  with `StepSpr=200` motor STEP pulses/rev and `StepGear=36`, producing
  `7200` output-shaft STEP pulses/rev.
- Hardware STOP button: `GPIO15`, `INPUT_PULLUP`, momentary to `GND`
- BOOT anchor-save button: `GPIO0`

Do not connect a powered brushed motor driver until its driver type, pinout,
brake/coast/enable behavior, current limit, fault/current signals, polarity,
idle behavior, and STOP behavior are documented and tested. Use
`docs/BRUSHED_MOTOR_DRIVER_INTAKE.md` to capture those facts before any powered
thruster connection.

Do not connect powered steering until the DRV8825 pinout, steps/rev, gear ratio,
current limit, torque limit, enable/sleep/reset wiring, idle behavior, and stop
behavior are documented and tested. Use
`docs/STEERING_DRIVER_INTAKE.md` to capture those facts before any powered
steering connection.

## Required Bench Hardware

- Current-limited DC supply for motor testing.
- Fuse or breaker sized below the weakest wire/driver element.
- Physical kill switch or removable power link reachable by the operator.
- Meter or logic analyzer for `PWM=7`, `DIR=8`, `DIR=10`, and steering outputs.
- Separate low-current logic supply proof before motor power is applied.
- Strain relief on battery/motor/driver wires.
- Insulated terminals; no exposed high-current contacts.
- Polarity labels on supply, driver, motor, and any quick disconnects.
- Thermal check method: finger-safe touch check for low power, IR thermometer or
  probe before longer runs.
- Prop removed or the motor mechanically unable to thrust during dry powered
  tests.

## Gate 0: Local And Bench Software

Run these before touching powered outputs:

```bash
tools/ci/run_local_prepowered_gate.sh
```

Equivalent manual sequence:

```bash
cd boatlock && platformio test -e native
cd boatlock && pio run -e esp32s3
python3 tools/sim/test_sim_core.py
python3 tools/sim/run_sim.py --check --json-out tools/sim/report.json
python3 tools/sim/run_sim.py --scenario-set all --check --json-out tools/sim/all_report.json
python3 tools/sim/test_soak.py
python3 tools/sim/run_soak.py --hours 6 --check --json-out tools/sim/soak_report.json
cd boatlock_ui && flutter analyze && flutter test
pytest tools/ci/test_*.py
```

Then flash and run the tracked bench path:

```bash
tools/hw/nh02/flash.sh
tools/hw/nh02/acceptance.sh --seconds 180
tools/hw/nh02/android-run-app-check.sh --status --wait-secs 130
tools/hw/nh02/android-run-app-check.sh --manual --wait-secs 130
tools/hw/nh02/android-run-app-check.sh --anchor --wait-secs 130
tools/hw/nh02/android-run-app-check.sh --sim --wait-secs 130
tools/hw/nh02/run-sim-suite.sh
tools/hw/nh02/android-run-app-check.sh --reconnect --wait-secs 130
tools/hw/nh02/android-run-app-check.sh --esp-reset --wait-secs 130
```

If hardware GPS is visible, also run:

```bash
tools/hw/nh02/android-run-app-check.sh --gps --wait-secs 180
```

## Gate 1: No-Load Output Instrumentation

Motor driver power disconnected. Steering motor/driver output disconnected
unless it is passive logic-level observation only.

Record each check with command, expected output, measured output, and pass/fail:

| Case | Expected motor output | Expected steering output |
| --- | --- | --- |
| Boot before BLE connect | `PWM=0`, direction stable/no chatter | idle/no stepping |
| BLE connected, `IDLE` | `PWM=0` | idle |
| `STOP` command | `PWM=0`, no pulse after STOP | idle, any active move cancelled |
| Hardware STOP press | same as `STOP` command | same as `STOP` command |
| `MANUAL_TARGET:0,0,1000` | `PWM=0` | no steering move |
| `MANUAL_TARGET:0,20,1000` | bounded PWM pulse only while lease is fresh | no steering move unless angle is non-zero |
| Manual lease expiry | `PWM=0` after TTL | idle |
| `MANUAL_OFF` | `PWM=0` | idle |
| `ANCHOR_ON` denied on bench | `PWM=0` | idle |
| `ANCHOR_OFF` | `PWM=0` | idle |
| `SIM_RUN` then `SIM_ABORT` | simulation smoke must not drive real outputs | idle |
| full on-device `sim_suite` | standard HIL suite must not drive real outputs | idle |
| BLE disconnect/reconnect | `PWM=0` | idle |
| ESP reset | `PWM=0` during and after reboot | idle |
| OTA begin/abort | `PWM=0` | idle |

Any unexpected pulse, repeated twitch, direction chatter, or output that
survives STOP is a blocker. Fix firmware/wiring before applying motor power.

## Gate 2: Low-Power Driver Proof

Only after Gate 1 passes:

1. Complete `docs/STEERING_DRIVER_INTAKE.md` for the current DRV8825 steering
   wiring and motor/mechanics.
2. Complete `docs/BRUSHED_MOTOR_DRIVER_INTAKE.md` for the actual brushed motor
   driver unless it has already been captured against this firmware commit.
3. Connect the driver with current-limited supply and no prop/load.
4. Verify polarity before energizing.
5. Set the supply current limit low enough that a wiring mistake cannot damage
   the driver or wiring.
6. Boot into `IDLE` and confirm no motion.
7. Send short manual target windows only.
8. Verify PWM steps and steering angle labels left/right.
9. Release controls and verify motion stops within the manual TTL.
10. Send BLE `STOP` and press hardware STOP; both must stop immediately.
11. Power-cycle and verify there is no auto-anchor or stored actuation.
12. Touch/measure driver, motor, wiring, and connectors after each short run.

Abort on heat, smell, voltage sag, unstable reset, reverse direction ambiguity,
or any output that continues after release/STOP.

## Gate 3: Dry Steering Integration

Do not enable thrust. Steering can be attached to the turn mechanism only if the
mechanism cannot hit a hard stop at speed.

- Mark physical bow-zero.
- Use setup to capture bow-zero only after the mechanics are known.
- Check manual left/right and release-to-idle.
- Command small target bearing changes and watch for hunting.
- Check cable wrap, mechanical limits, and jam behavior manually before powered
  steering.

If the steering hardware is not the current DRV8825-compatible STEP/DIR path,
stop here and add the real driver support before continuing.

## Gate 4: Wet Or Tethered Low-Power Test

- Use protected water or tank/tether.
- Keep thrust cap low and start manual-only.
- Verify STOP, app background/lock, BLE loss, reconnect, and manual TTL.
- Only then try anchor preflight, denial cases, and short quiet-profile holds.
- Keep a hard power-removal path within reach.
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

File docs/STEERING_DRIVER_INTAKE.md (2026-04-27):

# BoatLock Steering Driver Intake

Use this checklist before connecting or commanding the real steering drive. The
current firmware path assumes a DRV8825-compatible STEP/DIR driver on
`STEP=GPIO6` and `DIR=GPIO16`, with `StepSpr=200` motor STEP pulses/rev and
`StepGear=36` from the Vanchor gearbox, for `7200` output-shaft STEP pulses per
steering revolution. Capture the remaining hardware facts before powered
steering. If DRV8825 MODE pins are set for microstepping instead of full-step,
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

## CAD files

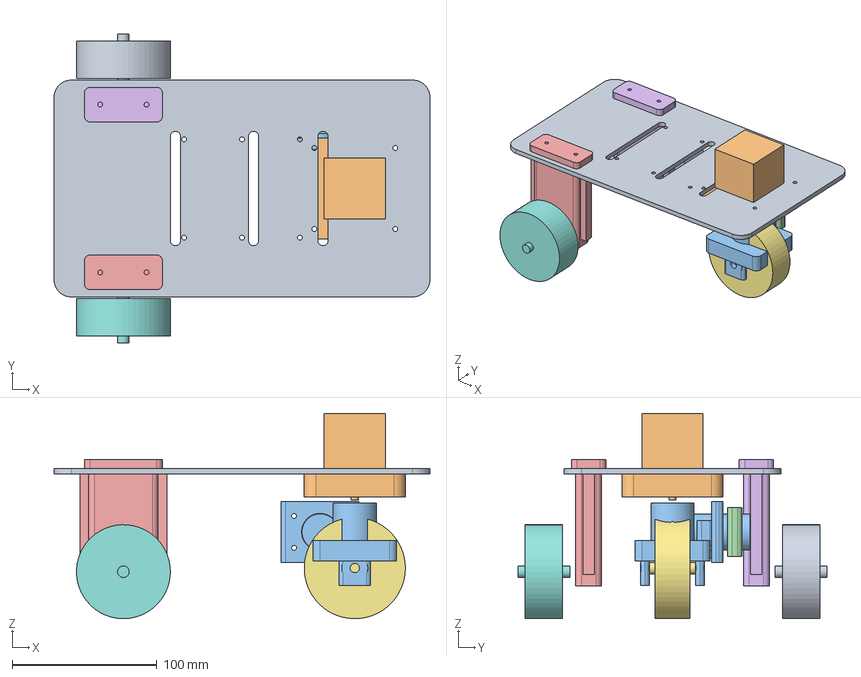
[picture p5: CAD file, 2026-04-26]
cad/ground_trike/out/boatlock_ground_trike.FCStd
260.0 x 214.0 x 142.0 mm
deck_plate
steering_bearing_carrier
front_fork_25ga
motor_cap_25ga
rear_axle_block_left
rear_axle_block_right
front_wheel_reference
rear_wheel_reference_left
rear_wheel_reference_right
nema17_reference
front_25ga_motor_reference

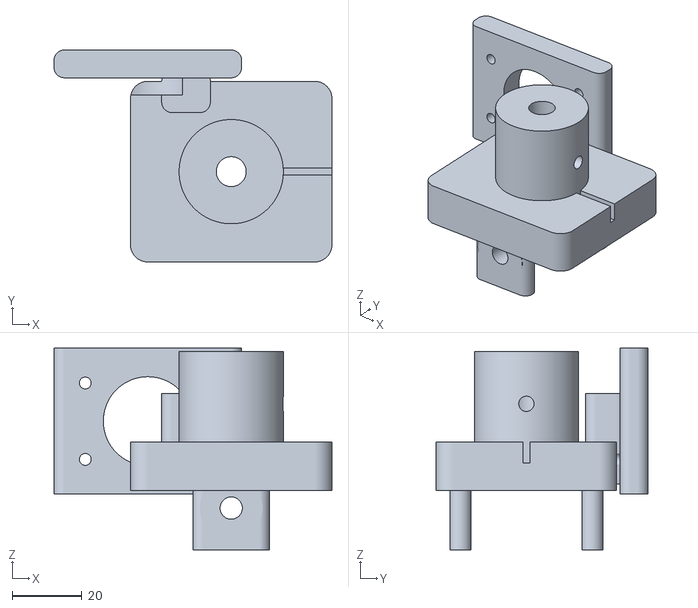
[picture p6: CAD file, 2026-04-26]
cad/ground_trike/out/stl/front_fork_25ga.stl
80.0 x 61.0 x 58.0

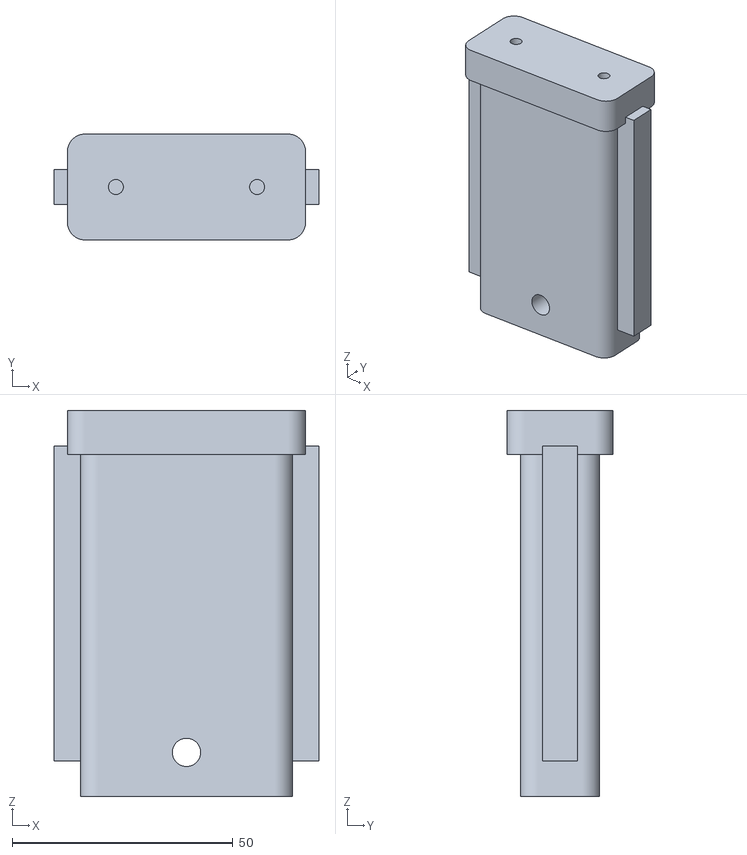
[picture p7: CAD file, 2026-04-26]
cad/ground_trike/out/stl/rear_axle_block.stl
60.0 x 24.0 x 87.5

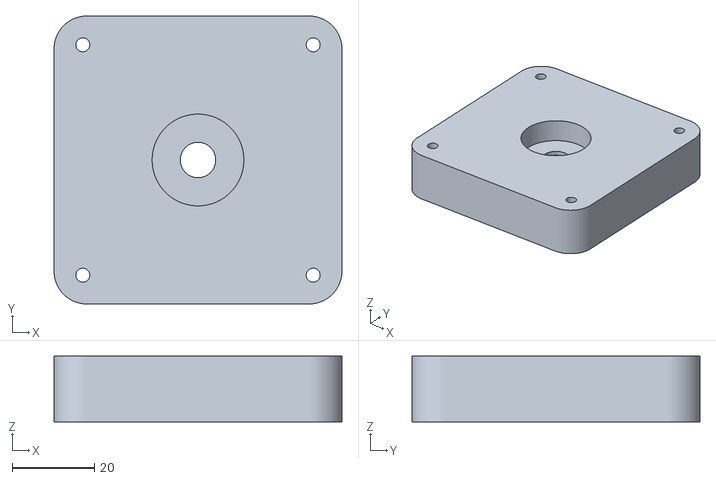
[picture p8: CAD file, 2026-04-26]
cad/ground_trike/out/stl/steering_bearing_carrier.stl
70.0 x 70.0 x 16.0

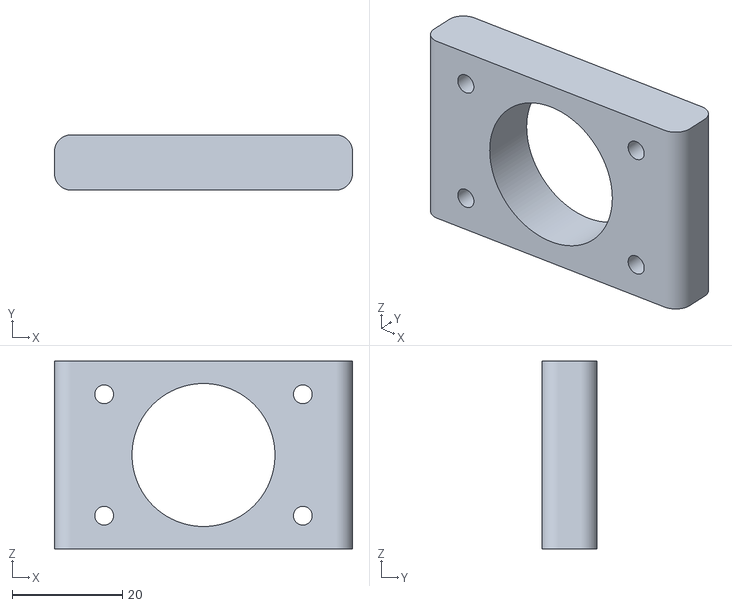
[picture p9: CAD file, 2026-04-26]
cad/ground_trike/out/stl/motor_cap_25ga.stl
54.0 x 10.0 x 34.0

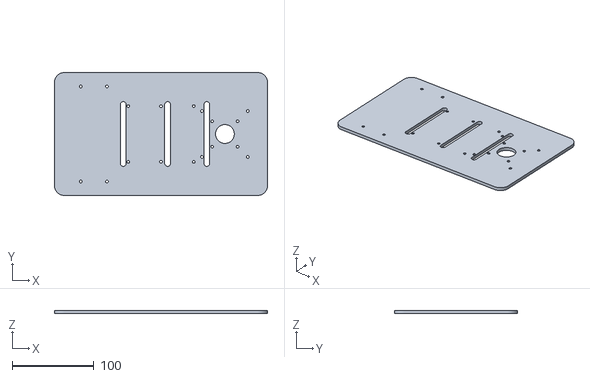
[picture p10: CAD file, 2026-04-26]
cad/ground_trike/out/stl/deck_plate.stl
260.0 x 150.0 x 4.00

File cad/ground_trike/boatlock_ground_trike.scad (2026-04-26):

/*
  BoatLock ground trike simulator, V0.

  Goal:
  - Child-car / tabletop scale ground simulator for BoatLock.
  - Two passive rear wheels.
  - One front wheel that both steers and drives.
  - NEMA17 steering motor drives an 8 mm kingpin through a coupler.
  - Wheel load is carried by 608 bearings, not by the NEMA17 shaft.

  OpenSCAD usage examples:
    openscad -o stl/deck_plate.stl -D 'part="deck_plate"' boatlock_ground_trike.scad
    openscad -o stl/steering_bearing_carrier.stl -D 'part="steering_bearing_carrier"' boatlock_ground_trike.scad
    openscad -o stl/front_fork_25ga.stl -D 'part="front_fork_25ga"' boatlock_ground_trike.scad
    openscad -o stl/rear_axle_block.stl -D 'part="rear_axle_block"' boatlock_ground_trike.scad
    openscad -o stl/motor_cap_25ga.stl -D 'part="motor_cap_25ga"' boatlock_ground_trike.scad
*/

$fn = 72;

part = "assembly"; // assembly, deck_plate, steering_bearing_carrier, front_fork_25ga, rear_axle_block, motor_cap_25ga

eps = 0.02;

// Main layout.
deck_len = 260;
deck_w = 150;
deck_t = 4;
deck_r = 12;
front_pivot_x = 78;
rear_axle_x = -82;
deck_z = front_wheel_od + 30;

// Hardware clearances.
m3_clear = 3.4;
m4_clear = 4.4;
m6_axle_clear = 6.4;
kingpin_clear = 8.6;
nema17_face = 42.3;
nema17_hole_spacing = 31.0;
nema17_center_bore = 23.0;
bearing_608_od = 22.3;
bearing_608_id_clear = 8.6;
bearing_608_depth = 7.2;

// Front wheel / motor reference.
front_wheel_od = 70;
front_wheel_w = 24;
front_axle_z = front_wheel_od / 2;
fork_leg_y = front_wheel_w / 2 + 7;
fork_leg_t = 6;
fork_crown_z = front_axle_z + 15;
fork_hub_h = 30;
motor_25ga_d = 25.6;
motor_25ga_len = 45;
motor_axis_x = -24;
motor_axis_y = fork_leg_y + 12;
motor_axis_z = front_axle_z + 25;

// Rear wheel reference.
rear_wheel_od = 65;
rear_wheel_w = 26;
rear_track = 178;
rear_drop = deck_z - rear_wheel_od / 2;

module rounded_rect_2d(l, w, r) {
  offset(r = r) square([l - 2 * r, w - 2 * r], center = true);
}

module rounded_box(l, w, h, r) {
  linear_extrude(height = h) rounded_rect_2d(l, w, r);
}

module rounded_box_center(l, w, h, r) {
  translate([0, 0, -h / 2]) rounded_box(l, w, h, r);
}

module slot_x(len, d, h) {
  hull() {
    translate([-len / 2, 0, 0]) cylinder(d = d, h = h);
    translate([ len / 2, 0, 0]) cylinder(d = d, h = h);
  }
}

module slot_y(len, d, h) {
  hull() {
    translate([0, -len / 2, 0]) cylinder(d = d, h = h);
    translate([0,  len / 2, 0]) cylinder(d = d, h = h);
  }
}

module deck_plate() {
  difference() {
    rounded_box(deck_len, deck_w, deck_t, deck_r);

    // NEMA17 and steering carrier center access.
    translate([front_pivot_x, 0, -eps])
      cylinder(d = nema17_center_bore, h = deck_t + 2 * eps);

    // NEMA17 face screws on top of deck.
    for (sx = [-1, 1], sy = [-1, 1]) {
      translate([
        front_pivot_x + sx * nema17_hole_spacing / 2,
        sy * nema17_hole_spacing / 2,
        -eps
      ])
        cylinder(d = m3_clear, h = deck_t + 2 * eps);
    }

    // Under-deck bearing carrier screws.
    for (sx = [-1, 1], sy = [-1, 1]) {
      translate([front_pivot_x + sx * 28, sy * 28, -eps])
        cylinder(d = m3_clear, h = deck_t + 2 * eps);
    }

    // Rear passive wheel block mount holes.
    for (side = [-1, 1], dx = [-16, 16]) {
      translate([rear_axle_x + dx, side * (deck_w / 2 - 17), -eps])
        cylinder(d = m3_clear, h = deck_t + 2 * eps);
    }

    // Electronics grid and cable slots.
    for (x = [-40, 0, 40], y = [-34, 34]) {
      translate([x, y, -eps]) cylinder(d = m3_clear, h = deck_t + 2 * eps);
    }
    for (x = [-46, 8, 56]) {
      translate([x, 0, -eps]) slot_y(72, 7, deck_t + 2 * eps);
    }
  }
}

module steering_bearing_carrier() {
  carrier_l = 70;
  carrier_h = 16;

  difference() {
    rounded_box(carrier_l, carrier_l, carrier_h, 8);

    // Kingpin clearance through both bearings.
    translate([0, 0, -eps])
      cylinder(d = bearing_608_id_clear, h = carrier_h + 2 * eps);

    // 608 bearing pockets. Print and ream/sand for real bearings.
    translate([0, 0, -eps])
      cylinder(d = bearing_608_od, h = bearing_608_depth + eps);
    translate([0, 0, carrier_h - bearing_608_depth])
      cylinder(d = bearing_608_od, h = bearing_608_depth + eps);

    // Deck mount screws.
    for (sx = [-1, 1], sy = [-1, 1]) {
      translate([sx * 28, sy * 28, -eps])
        cylinder(d = m3_clear, h = carrier_h + 2 * eps);
    }
  }
}

module front_fork_25ga() {
  /*
    The wheel axle is a 6 mm steel shaft between fork legs.
    The CAD leaves a 25GA/25D gearmotor saddle on one side of the rotating fork.
    Default drive assumption: motor drives the wheel axle with a small belt or
    printed spur stage. This keeps wheel radial load off the motor output shaft.
  */
  difference() {
    union() {
      // Kingpin clamp boss. Uses 8 mm shaft/bolt through 608 bearings.
      translate([0, 0, fork_crown_z])
        cylinder(d = 30, h = fork_hub_h);

      // Crown ties the two legs and the steering boss together.
      translate([0, 0, fork_crown_z - 3])
        rounded_box_center(58, 52, 14, 5);

      // Fork legs.
      for (y = [-fork_leg_y, fork_leg_y]) {
        translate([0, y, (front_axle_z + fork_crown_z) / 2 - 4])
          rounded_box_center(22, fork_leg_t, fork_crown_z - front_axle_z + 16, 3);

        translate([0, y, front_axle_z])
          rotate([90, 0, 0])
            cylinder(d = 18, h = fork_leg_t, center = true);
      }

      // Side motor mount pad for 25GA/25D class gearmotor.
      translate([motor_axis_x, motor_axis_y, motor_axis_z])
        rounded_box_center(54, 8, 42, 3);

      // Extra rib back to the crown for belt tension loads.
      translate([-13, motor_axis_y - 8, (motor_axis_z + fork_crown_z) / 2])
        rounded_box_center(14, 12, abs(fork_crown_z - motor_axis_z) + 16, 3);
    }

    // 8 mm kingpin.
    translate([0, 0, fork_crown_z - 10])
      cylinder(d = kingpin_clear, h = fork_hub_h + 22);

    // Split relief for the kingpin clamp. Add M4 screw/nut in real print.
    translate([15, -1.0, fork_crown_z - 2])
      cube([20, 2, fork_hub_h + 8]);
    translate([13, 0, fork_crown_z + fork_hub_h / 2])
      rotate([0, 90, 0])
        cylinder(d = m4_clear, h = 28, center = true);

    // Front wheel axle.
    translate([0, 0, front_axle_z])
      rotate([90, 0, 0])
        cylinder(d = m6_axle_clear, h = 2 * fork_leg_y + 22, center = true);

    // 25GA motor saddle and two face-screw slots.
    translate([motor_axis_x, motor_axis_y, motor_axis_z])
      rotate([90, 0, 0])
        cylinder(d = motor_25ga_d, h = 18, center = true);

    for (sx = [-1, 1], sz = [-1, 1]) {
      translate([motor_axis_x + sx * 18, motor_axis_y, motor_axis_z + sz * 11])
        rotate([90, 0, 0])
          cylinder(d = m3_clear, h = 18, center = true);
    }
  }
}

module motor_cap_25ga() {
  difference() {
    rounded_box_center(54, 10, 34, 3);

    // Clamp saddle. Sand to fit the exact motor can.
    rotate([90, 0, 0])
      cylinder(d = motor_25ga_d + 0.3, h = 14, center = true);

    for (sx = [-1, 1], sz = [-1, 1]) {
      translate([sx * 18, 0, sz * 11])
        rotate([90, 0, 0])
          cylinder(d = m3_clear, h = 14, center = true);
    }
  }
}

module rear_axle_block() {
  difference() {
    union() {
      // Axle-to-deck drop bracket for the high steering stack.
      translate([0, 0, rear_drop / 2])
        rounded_box_center(48, 18, rear_drop + 20, 4);
      translate([0, 0, rear_drop + 5])
        rounded_box_center(54, 24, 10, 4);
      translate([0, 0, 0])
        rotate([90, 0, 0])
          cylinder(d = 19, h = 18, center = true);
      for (x = [-11, 11]) {
        translate([x, 0, rear_drop / 2])
          rounded_box_center(38, 8, rear_drop + 4, 3);
      }
    }

    // M6 shoulder bolt / 6 mm shaft for passive rear wheel.
    translate([0, 0, 0])
      rotate([90, 0, 0])
        cylinder(d = m6_axle_clear, h = 26, center = true);

    // Two M3 mount screws into the deck.
    for (x = [-16, 16]) {
      translate([x, 0, rear_drop + 5])
        cylinder(d = m3_clear, h = 18, center = true);
    }
  }
}

module nema17_reference() {
  color([0.2, 0.2, 0.22, 0.35]) {
    translate([0, 0, 19]) cube([nema17_face, nema17_face, 38], center = true);
    translate([0, 0, -10]) cylinder(d = 5, h = 24);
    cylinder(d = 22, h = 2);
  }
}

module wheel_reference(d, w, axle_d) {
  color([0.05, 0.05, 0.05, 0.35])
    rotate([90, 0, 0]) cylinder(d = d, h = w, center = true);
  color([0.8, 0.8, 0.8, 0.35])
    rotate([90, 0, 0]) cylinder(d = axle_d, h = w + 10, center = true);
}

module motor_25ga_reference() {
  color([0.6, 0.55, 0.48, 0.35])
    translate([motor_axis_x, motor_axis_y, motor_axis_z])
      rotate([90, 0, 0])
        cylinder(d = 25, h = motor_25ga_len, center = true);
}

module assembly() {
  // Ground reference.
  color([0.85, 0.85, 0.85, 0.18])
    translate([0, 0, -0.5]) cube([310, 230, 1], center = true);
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

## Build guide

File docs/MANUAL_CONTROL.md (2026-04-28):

# Manual Control Mode

Manual control is part of the product surface for phone and future BLE remote
controllers.

## Current Command Contract

The firmware accepts only the atomic
`MANUAL_TARGET:<angleDeg>,<throttlePct>,<ttlMs>` lease command plus
`MANUAL_OFF`. `angleDeg` is the selected steering vector from `-90` to `+90`
degrees relative to bow-forward, and `throttlePct` is the brushed-motor PWM
request. Each accepted `MANUAL_TARGET` belongs to one controller source,
disables Anchor mode on entry, and refreshes that source's manual deadman TTL.
A competing source cannot replace a live manual lease until the lease expires
or `MANUAL_OFF`/`STOP` clears it.
The shipped phone UI uses `ttlMs=1000` and refreshes the selected angle/speed
while either value is non-zero.

If manual updates stop, the TTL expires, Manual mode exits, and the normal
quiet-output path stops stepper and thruster output.

## Multi-Client Ownership Design

This is the required design gate before accepting a future BLE remote as a
second real controller. Multi-central BLE transport is allowed for discovery and
telemetry, but transport support does not grant control authority.

Controller identity is assigned by firmware, not self-declared in command text.
Each connected central needs a connection-local identity made from the BLE
connection handle, sanitized peer address when available, and a monotonic
connection generation. A reconnect creates a new controller identity and must
acquire control again. If the BLE stack cannot provide a stable peer address,
the handle plus generation is still sufficient for one boot session; identities
are not persisted across boots.

Read-only telemetry clients are allowed to coexist. They may subscribe to `34cd`
live telemetry and `78ab` logs and may use transport-only `STREAM_START`,
`STREAM_STOP`, and `SNAPSHOT`. They do not own a control lease and must not send
actuation, mode, settings, OTA, simulation, or injected-sensor commands.

At most one eligible control owner may exist at a time. The control lease stores
controller identity, role (`app` or `remote`), acquire time, last refresh, and
expiry. The first eligible control command can acquire the lease only when no
live owner exists. Accepted owner
commands and owner `HEARTBEAT` refresh the lease. Commands from a different
controller while the lease is live are rejected with a stable busy reason and
have no side effects.

Takeover is conservative. A different controller can take over only after the
current owner lease expires, the owner disconnects and the runtime has gone
quiet, or emergency `STOP` clears the owner. There is no silent transfer to a
connected telemetry client. Owner disconnect during Manual or Anchor is a
control-link loss: outputs go quiet and the runtime must not resume actuation
because another client is still connected.

The phone app is the full product controller for anchor save/enable/disable,
jog, hold-heading, manual, STOP, and allowed settings and OTA flows. A
future BLE remote is constrained by default to deadman manual control, ordinary
Anchor off, owner heartbeat, and emergency STOP. It must not save or move the
anchor point, change settings, start OTA, run HIL, inject sensors, or use setup
or dev/HIL commands unless a later product decision explicitly adds and tests
those remote surfaces.

Manual control is a sublease of the control owner. The first accepted
`MANUAL_TARGET` may acquire both the control lease and manual deadman lease
atomically when no owner exists. After that, only the control owner can refresh
manual TTL with `MANUAL_TARGET` or stop manual output with `MANUAL_OFF`. Manual TTL
expiry stops Manual output; it does not grant takeover to a competing source.
Control lease expiry, owner disconnect, or `STOP` clears any active manual
lease.

STOP priority is absolute at the safety layer. Physical STOP always wins and
clears control ownership, manual lease state, Anchor, and outputs. BLE `STOP`
does not require ownership, so a secondary controller can stop a live owner.

Before accepting an implementation, tests must cover:

- two connected telemetry clients receiving live frames/logs while neither can
  control without acquiring ownership
- owner acquisition, refresh, expiry, disconnect cleanup, and busy rejection for
  Anchor, Manual, settings, OTA, and dev/HIL commands
- remote role allowlist: manual, Anchor off, heartbeat, and STOP accepted;
  anchor save/jog/settings/OTA/HIL/sensor injection rejected
- manual sublease behavior: same-owner refresh, non-owner refresh rejection,
  TTL quieting, `MANUAL_OFF`, lease expiry, and reconnect
- STOP preemption from hardware and from a non-owner BLE client
- Android or bench two-central smoke where phone telemetry stays read-only while
  a remote/harness owns manual, and the reverse busy path is observable

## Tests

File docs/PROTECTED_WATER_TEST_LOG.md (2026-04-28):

# BoatLock Protected-Water Test Log

Use one copy of this log per powered bench, tank, tether, or protected-water
session. This is the required external measurement path until BoatLock has
real battery/current/power telemetry.

## Session

- Date/time:
- Location/water body:
- Operators:
- Recovery method:
- Weather/wind/current/wave estimate:
- Firmware commit:
- App commit:
- Boat/load mass estimate:
- Motor driver model:
- Steering driver/mechanics:
- Battery/supply:
- Fuse/breaker rating:
- Physical kill path:

## Pre-Run Gate

| Check | Result | Notes |
| --- | --- | --- |
| `docs/POWERED_BENCH_CHECKLIST.md` Gate 0 passed |  |  |
| `tools/ci/run_local_prepowered_gate.sh` passed on this commit |  |  |
| Correct firmware profile flashed for this phase |  |  |
| `nh02` acceptance passed after flash |  |  |
| Android status/manual/reconnect smokes passed after flash |  |  |
| No-load output instrumentation passed |  |  |
| DRV8825/Vanchor steering intake complete |  |  |
| Prop/load safe for current phase |  |  |
| STOP command tested before launch |  |  |
| Hardware STOP tested before launch |  |  |
| Manual release-to-stop tested before launch |  |  |
| BLE reconnect tested before launch |  |  |
| microSD inserted and `[SD] logger ready=1` seen after boot |  |  |
| GNSS fix visible |  |  |
| Heading fresh |  |  |
| Anchor preflight blocks/accepts as expected |  |  |

## Phase Advancement Rules

Do not advance to the next phase in the same session unless every previous phase
has a clean pass, the operators agree the recovery path is still available, and
the battery/supply, driver, wiring, and motor temperatures remain within the
recorded limits. A phase with any abort condition becomes the last phase of the
session.

| Phase | Entry condition | Maximum first-run exposure | Pass condition | Next phase allowed |
| --- | --- | --- | --- | --- |
| Float telemetry only | Outputs disabled or physically unable to thrust | 5 min | BLE, GNSS, heading, readiness, logs, display, and STOP behave as expected with no actuation | Manual low-power |
| Manual low-power pulses | Current limit set low, hard power removal ready | 1 s pulses, then 3 s pulses | Press-and-hold only, release-to-stop, BLE loss quiets output, reconnect does not resume motion | Steering-only |
| Steering-only | Thrust disabled; bow-zero and travel limits proven | 10 small left/right moves | Direction labels correct, no hunting, no hard-stop contact, idle/hold behavior safe | Anchor preflight |
| Anchor preflight | Saved anchor and current fix visible; quiet profile selected | No sustained thrust until denied cases are observed | Denied reasons are correct; accepted only with fresh heading and good GNSS | Quiet anchor 30-60 s |
| Quiet anchor 30-60 s | Recovery boat/tether ready; low thrust cap | One 30 s hold, then one 60 s hold | No repeated twitching, no saturation, STOP/manual recovery works | Longer hold |
| Longer hold | Previous quiet holds clean | 5 min, then 10 min | Drift stays bounded, thermal/current behavior stable, no failsafe except intentional abort | Controlled disturbance |
| Controlled disturbance | Operators explicitly approve disturbance | One small disturbance at a time | System remains bounded or aborts quietly; STOP still preempts | End session or repeat later |

## Required Captures

- Photo of wiring, fuse/breaker, kill path, battery/supply, motor driver, and
  steering driver before power is applied.
- Screenshot or exported app state before each phase: readiness, GNSS,
  heading, anchor, failsafe, manual lease, and motor readiness.
- microSD `/boatlock/*.jsonl` logs for the whole session, plus Serial/BLE logs
  for boot markers, connection state, and STOP tests.
- External voltage/current readings for idle, pulse, peak, and post-run states.
- Track/drift notes for every anchor phase, even if the run is aborted early.
- Weather and water notes: wind estimate, current estimate, wave/wake exposure,
  and nearby traffic.

## Power Measurements

Record external meter/clamp/supply readings at each phase. If using a bench
supply, record both set limits and observed values.

| Phase | Duration | Voltage start/end | Current idle/peak | Power peak | Fuse/breaker | Battery/supply temp | Driver temp | Motor temp | Notes |
| --- | --- | --- | --- | --- | --- | --- | --- | --- | --- |
| Float telemetry only |  |  |  |  |  |  |  |  |  |
| Manual low-power pulses |  |  |  |  |  |  |  |  |  |
| Steering-only |  |  |  |  |  |  |  |  |  |
| Anchor preflight denied |  |  |  |  |  |  |  |  |  |
| Quiet anchor 30-60 s |  |  |  |  |  |  |  |  |  |
| Longer hold |  |  |  |  |  |  |  |  |  |
| Disturbance/abort |  |  |  |  |  |  |  |  |  |

## Event Log

Record every command, mode change, STOP, disconnect, failsafe, or unexpected
motion. Use exact wrapper/command names where possible.

| Time | Command/event | App mode/status | GNSS Q | Heading Q | Distance/bearing | PWM/current | Result |
| --- | --- | --- | --- | --- | --- | --- | --- |
|  |  |  |  |  |  |  |  |

## Abort Conditions

Abort the session immediately on any of these:

- unexpected actuation
- control remains active after release or STOP
- hardware STOP has no immediate effect
- BLE loss leaves controls enabled from stale state
- compass loss or repeated heading jumps
- GNSS jump or stale fix during anchor enable
- steering hunting, jam, cable wrap, or hard-stop contact
- unbounded PWM/current saturation
- voltage sag, brownout, reset, heat, smell, water ingress, or wiring movement
- any operator uncertainty

## Post-Run Review

- Final battery/supply voltage:
- Max observed current:
- Max observed power:
- Max driver/motor/wiring temperature:
- Any fuse/breaker/kill switch action:
- Any reset/brownout:
- Any failsafe reason:
- Track/drift notes:
- Firmware/app changes required before next run:
- Next allowed phase:
- Simulator calibration data extracted:
- Decision: repeat same phase / advance / stop until fix:

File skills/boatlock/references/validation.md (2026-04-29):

# Validation Reference

## Pick The Smallest Relevant Check

- Firmware logic change:
  - run targeted native tests first
  - build the affected firmware env if the change touches production code
- BLE command or telemetry change:
  - native BLE command tests
  - Flutter tests for parsing/UI
  - update `docs/BLE_PROTOCOL.md`
  - if the app must be installed before BLE OTA can update already-deployed
    firmware, keep enough parser bridge for the currently installed live-frame
    version to start OTA and prove the rollout through `tools/hw/nh02/deploy.sh`
- GNSS, anchor-control, or safety change:
  - native tests
  - HIL simulation checks if behavior is control-loop sensitive
- Settings/schema change:
  - update `docs/CONFIG_SCHEMA.md`
  - keep `Settings::VERSION` and CI schema checks aligned
- NVS/EEPROM write-policy change:
  - audit all `settings.save()` call sites, not only the file currently being changed
  - remember that `Settings::load()` can persist on boot during migration/CRC/normalization flows
  - cover both `test_settings` and the command/runtime tests that exercise the changed write paths
- Version or release-note change:
  - keep `boatlock/main.cpp`, `CHANGELOG.md`, `docs/releases/`, and CI version checks aligned
- Release process change:
  - keep `docs/RELEASE_PROCESS.md`, `.github/workflows/ci.yml`, release branch checks, and app firmware source defines aligned

## GitHub Actions And Release API Checks

- GitHub Actions and GitHub Release proof must come from GitHub API data, not
  from browser pages, local artifacts, or assumptions from `git push` output.
- `gh` is not required on this host. Use the GitHub REST API through `curl`
  and the existing git credential helper; do not print the token.
- If API access fails only inside the sandbox with network/permission errors,
  rerun the same API probe with host access before treating GitHub as broken.
- Canonical credential setup for one shell session:

```sh
GITHUB_TOKEN="$(
  printf 'protocol=https\nhost=github.com\n\n' |
    git credential fill |
    awk -F= '$1 == "password" { print $2 }'
)"
```

- Find the workflow run for a pushed branch, release branch, tag, or SHA:

```sh
REF="v0.2.7"
curl -fsS \
  -H "Accept: application/vnd.github+json" \
  -H "Authorization: Bearer ${GITHUB_TOKEN}" \
  "https://api.github.com/repos/dslimp/boatlock/actions/runs?per_page=50" |
  jq -r --arg ref "${REF}" '
    .workflow_runs[]
    | select(.head_branch == $ref or .head_sha == $ref)
    | [.id, .name, .status, .conclusion, .head_branch, .head_sha, .html_url]
    | @tsv
  '
```

- Inspect failed or pending jobs for a run before guessing:

```sh
RUN_ID="25080503445"
curl -fsS \
  -H "Accept: application/vnd.github+json" \
  -H "Authorization: Bearer ${GITHUB_TOKEN}" \
  "https://api.github.com/repos/dslimp/boatlock/actions/runs/${RUN_ID}/jobs?per_page=100" |
  jq -r '.jobs[] | [.name, .status, .conclusion, .html_url] | @tsv'
```

- Verify the published release and required OTA assets:

```sh
TAG="v0.2.7"
curl -fsS \
  -H "Accept: application/vnd.github+json" \
  -H "Authorization: Bearer ${GITHUB_TOKEN}" \
  "https://api.github.com/repos/dslimp/boatlock/releases/tags/${TAG}" |
  jq '{tag_name, draft, prerelease, target_commitish, asset_count: (.assets | length), assets: [.assets[].name]}'
```

- Verify the app-facing firmware manifest, because the phone `Последняя с
  GitHub` button depends on this file:

```sh
TAG="v0.2.7"
curl -fsSL \
  -H "Authorization: Bearer ${GITHUB_TOKEN}" \
  "https://github.com/dslimp/boatlock/releases/download/${TAG}/manifest.json" |
  jq '{repo, branch, channel, firmwareVersion, platformioEnv, commandProfile, workflowRunId, binaryUrl, size, sha256, gitSha}'
```

- A release is not proven until the tag workflow is `completed/success`, the
  GitHub Release is not draft/prerelease, and the assets include at least
  `manifest.json`, `firmware-esp32s3.bin`, and `boatlock-app.apk`.

## Common Commands

- Local pre-powered validation gate:
  - `tools/ci/run_local_prepowered_gate.sh`
- Firmware build:
  - `cd boatlock && pio run -e esp32s3`
- Acceptance firmware profile build:
  - `cd boatlock && pio run -e esp32s3_acceptance`
- Normal phone BLE OTA firmware update:
  - operator path A: Settings -> `Файл на телефоне` with a local
    `firmware.bin` selected on the Android phone
  - operator path B: Settings -> `Последняя с GitHub` against the latest
    GitHub Release for `dslimp/boatlock`
  - bench automation only: `tools/hw/nh02/deploy.sh`
  - reuse already-built firmware/APK through the same path: `tools/hw/nh02/deploy.sh --no-build`
  - low-level app-check when bypassing the build wrapper is intentional: `tools/hw/nh02/android-run-app-check.sh --ota --ota-firmware boatlock/.pio/build/esp32s3/firmware.bin --wait-secs 1800`
  - remember the release APK is installed before the firmware upload, so app-side
    telemetry parsing must still decode the currently installed firmware well
    enough to receive first telemetry and launch OTA
  - do not add operator-facing firmware URL/SHA fields back to Settings; the
    URL/SHA path is hidden bench automation only
  - USB flash is only the seed/recovery path when the target lacks an OTA-capable image or cannot reconnect over BLE
  - if BLE discovery may take time, add `--wait-secs 1800`; the wrapper wait
    starts before scan/connect and can expire during upload when advertising
    appears late
- Latest-release phone bridge:
  - release app builds use the built-in `dslimp/boatlock` GitHub release source
  - local shortcuts: `tools/android/build-app-apk.sh` and `tools/macos/build-app.sh`
  - public latest-release bench proof: `tools/hw/nh02/android-run-app-check.sh --ota-latest-release --wait-secs 1800`
  - local temporary-manifest bench proof for unpublished firmware: `tools/hw/nh02/android-run-app-check.sh --ota-latest-release --ota-firmware boatlock/.pio/build/esp32s3/firmware.bin`
- Full native tests:
  - `cd boatlock && platformio test -e native`
- Do not run multiple `platformio test -e native ...` commands in parallel against the same checkout/build directory. PlatformIO shares `.pio/build/native`, and parallel suites can kill or corrupt each other; run suites sequentially or use isolated worktrees/build dirs.
- Example targeted native suites:
  - `cd boatlock && platformio test -e native -f test_ble_command_handler`
  - `cd boatlock && platformio test -e native -f test_gnss_quality_gate`
  - `cd boatlock && platformio test -e native -f test_hil_sim`
  - `cd boatlock && platformio test -e native -f test_settings`
- Flutter tests:
  - `cd boatlock_ui && flutter test`
- App release builds:
  - Android and macOS app wrappers build release artifacts only.
  - Do not add separate debug or alternate app variants; the release app includes
    setup controls hidden behind the Settings `Настройка оборудования` switch.
  - Local Android release builds auto-source
    `~/.boatlock/android-release-signing.env` when it exists, so `deploy.sh`
    and app-check install APKs signed with the same stable key as GitHub
    Releases. If that env file is absent, non-tag builds may still fall back to
    debug signing.
  - Android APK output is `boatlock_ui/build/app/outputs/flutter-apk/app-release.apk`.
  - macOS app output is `boatlock_ui/build/macos/Build/Products/Release/BoatLock.app`.
- Offline simulation harness:
  - `python3 tools/sim/test_sim_core.py`
  - `python3 tools/sim/run_sim.py --check --json-out tools/sim/report.json`
  - `python3 tools/sim/test_soak.py`
  - `python3 tools/sim/run_soak.py --hours 6 --check --json-out tools/sim/soak_report.json`
- NH02 hardware bench:
  - `tools/hw/nh02/install.sh`
  - `tools/hw/nh02/deploy.sh`
  - `tools/hw/nh02/deploy.sh --no-build`
  - `tools/hw/nh02/android-run-app-check.sh --ota --ota-firmware boatlock/.pio/build/esp32s3/firmware.bin --wait-secs 1800` for the lower-level OTA check
  - `tools/hw/nh02/flash.sh` (USB seed/recovery)
  - `tools/hw/nh02/flash.sh --profile acceptance`
  - `tools/hw/nh02/acceptance.sh`
  - `pytest -q tools/hw/nh02/test_acceptance.py`
  - `tools/hw/nh02/monitor.sh`
  - `tools/hw/nh02/status.sh`
  - `tools/hw/nh02/android-install.sh`
  - `tools/hw/nh02/android-install-app.sh`
  - `tools/hw/nh02/android-status.sh`
  - `tools/hw/nh02/android-wifi-debug.sh`
  - rerun `install.sh` after changing the tracked service unit or remote flash helper
- microSD logger hardware proof:
  - flash a build with a FAT-formatted microSD inserted
  - require `[SD] logger ready=1`
  - verify display redraws still work
  - verify `/boatlock/*.jsonl` grows on the card
  - for rotation/low-space work, test file rotation or low-space deletion on real media before water use
- Android USB + BLE app checks:
  - `tools/android/status.sh`
  - `tools/android/build-app-apk.sh`
  - `tools/android/run-app-check.sh`
  - `tools/android/run-smoke.sh`
  - `tools/hw/nh02/android-run-app-check.sh --manual --wait-secs 130`
  - `tools/hw/nh02/android-run-app-check.sh --compass --wait-secs 130`
  - `tools/hw/nh02/android-run-app-check.sh --gps --wait-secs 180`
  - `tools/hw/nh02/android-run-app-check.sh --ota --ota-firmware boatlock/.pio/build/esp32s3/firmware.bin`
  - `tools/hw/nh02/android-run-app-check.sh --ota --ota-firmware boatlock/.pio/build/esp32s3/firmware.bin --wait-secs 1800`
  - `tools/hw/nh02/android-run-app-check.sh --ota-latest-release --wait-secs 1800`
  - `tools/hw/nh02/android-run-app-check.sh --sim-suite --wait-secs 1800`
  - `tools/hw/nh02/run-sim-suite.sh`
  - `tools/hw/nh02/android-run-app-check.sh --reconnect --wait-secs 130`
  - `tools/hw/nh02/android-run-app-check.sh --esp-reset --wait-secs 130`
  - `tools/hw/nh02/android-run-smoke.sh --manual --wait-secs 130`
  - `tools/hw/nh02/android-run-smoke.sh --compass --wait-secs 130`
  - `tools/hw/nh02/android-run-smoke.sh --gps --wait-secs 180`
  - `tools/hw/nh02/android-run-smoke.sh --reconnect --wait-secs 130`
  - `tools/hw/nh02/android-run-smoke.sh --esp-reset --wait-secs 130`
- App check mode constants and parser live in `boatlock_ui/lib/smoke/ble_smoke_mode.dart`.
- Android checks build `lib/main.dart` once and pass runtime extras to the same release app; do not use alternate entrypoints or compile-time switches.
- Shell app-check mode allowlist lives in `tools/android/common.sh`; do not duplicate hard-coded mode case lists in individual wrappers.
- When the check mode contract changes, run its Flutter unit test, `pytest -q tools/ci/test_android_smoke_modes.py`, and `tools/android/build-app-apk.sh` at minimum.
- CI helper tests:
  - `pytest tools/ci/test_*.py`
- Quick audit for persistence call sites:
  - `rg -n "settings\\.save\\(" boatlock`

## Release/Dev/HIL Gate Validation

Firmware command enforcement is implemented in the shared BLE command path. PlatformIO profile aliases and the `nh02` flash wrapper profile report select which command scopes are compiled into the firmware command gate.

Profile rules:

- `release` profile: accepts release commands, including setup, BLE OTA, and
  `SIM_*`, and rejects dev/HIL commands such as `SET_PHONE_GPS`.
- `acceptance` profile: accepts release plus dev/HIL for broad bench
  validation.
- `esp32s3` is the normal firmware build and release artifact source.
- `esp32s3_acceptance` is the explicit dev/HIL profile alias.
- `tools/hw/nh02/flash.sh --profile acceptance` maps to
  `esp32s3_acceptance`; the wrapper defaults to `esp32s3`.
- `BOATLOCK_PIO_ENV=acceptance` maps to `esp32s3_acceptance`; an empty or
  unknown `BOATLOCK_PIO_ENV` is an error.
- `esp32s3_bno08x_sh2_uart` uses the normal command profile with SH2-UART
  compass support.
- `gpio_probe` and `uart_rvc_probe_rx12` are debug probe builds with no release
  artifact role.

Minimum validation order after profile-gate changes:

1. Local docs/static checks:
   - `bash -n tools/hw/nh02/flash.sh`
   - `git diff --check -- boatlock/platformio.ini tools/hw/nh02/flash.sh docs/BLE_PROTOCOL.md docs/HARDWARE_NH02.md skills/boatlock/references/validation.md boatlock/TODO.md`
   - `rg -n "esp32s3_acceptance|release|dev/HIL|SIM_|OTA|BOATLOCK_PIO_ENV|PlatformIO|nh02" boatlock/platformio.ini tools/hw/nh02/flash.sh docs/BLE_PROTOCOL.md docs/HARDWARE_NH02.md skills/boatlock/references/validation.md boatlock/TODO.md`
2. Local firmware/unit checks, run sequentially in one build directory:
   - native BLE command tests cover each profile's allow/deny matrix
   - native HIL tests cover `SIM_*` as a release-scope safe simulation mode
   - each PlatformIO firmware profile builds without relying on stale `.pio` artifacts
3. Normal firmware bench checks:
   - flash the normal firmware through `tools/hw/nh02/flash.sh`
   - run `tools/hw/nh02/acceptance.sh`
   - prove `SET_PHONE_GPS` is rejected with stable gate logs and no output motion
   - run Android `sim` smoke/check and verify `SIM` telemetry without motor/stepper output
4. BLE OTA bench checks:
   - build the normal firmware and update the target through phone BLE OTA by running `tools/hw/nh02/deploy.sh`
   - prove telemetry recovers after the ESP32 reboots into the uploaded image
5. Release-profile full HIL bench checks:
   - run `tools/hw/nh02/run-sim-suite.sh` when the standard full on-device HIL suite is required; it runs `SIM_LIST`, every listed scenario through `SIM_RUN:<id>,0`, `SIM_STATUS`, and `SIM_REPORT` on the normal firmware
6. Recovery check:
   - flash the normal firmware again through `tools/hw/nh02/flash.sh` and confirm the normal BLE reconnect/manual/anchor readiness smoke still uses the release surface only

Risk review items for the rollout:

- An acceptance image must not be left on the boat for water use because it exposes injected sensor and HIL commands.
- Wrapper output must distinguish profile-gated rejection from BLE timeout and parser failure.

## Useful Test Inventory

- Native firmware test directories live under `boatlock/test/`.
- High-signal suites for protocol/runtime work:
  - `test_ble_command_handler`
  - `test_gnss_quality_gate`
  - `test_anchor_supervisor`
  - `test_hil_sim`
  - `test_settings`
- Flutter tests live under `boatlock_ui/test/`.

## Version And Schema Sync

- Firmware version string lives in `boatlock/main.cpp` as `kFirmwareVersion`.
- Version consistency is checked by `tools/ci/check_firmware_version.py`.
- Release tags use `vX.Y.Z`, are cut from `release/vX.Y.x`, and are checked by `tools/ci/check_release_ref.py`.
- GitHub Releases, not GitHub Pages, are the standard release delivery channel.
- Settings schema version lives in `boatlock/Settings.h` as `Settings::VERSION`.
- Schema consistency is checked by `tools/ci/check_config_schema_version.py`.
- Release-note generation helpers live under `tools/ci/generate_release_notes.py`.

## Documentation Sync Rules

- If you change commands, telemetry fields, or status reasons, update `docs/BLE_PROTOCOL.md`.
- If you change settings defaults, ranges, or schema version, update `docs/CONFIG_SCHEMA.md`.
- If you change NVS/EEPROM write policy or persistence semantics, update the skill references and any operator docs that mention save behavior.
- If you change user-visible firmware behavior, update `CHANGELOG.md` and the relevant release note when appropriate.
- When prose docs disagree with code, fix the docs in the same change instead of preserving the mismatch.

## Wrapper Hygiene

- Repo bash wrappers must work under macOS bash 3.2 with `set -u`; do not expand empty arrays directly as `"${ARGS[@]}"`. Branch on `${#ARGS[@]}` before passing optional arg arrays.

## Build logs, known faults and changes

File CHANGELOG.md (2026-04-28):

# Changelog

All notable changes to this project will be documented in this file.

## [0.2.7] - 2026-04-29
### Removed
- Removed the app-layer BLE pairing/auth command wrapper, owner-secret UI,
  security telemetry, and related compatibility tests.
- Removed the gated Wi-Fi HTTP `pull-update` debug deploy path so the normal
  firmware update routes are only phone-local firmware file and latest GitHub
  Release from the release app.

### Changed
- Live BLE telemetry is now binary frame v5 at 65 bytes after dropping security
  fields.
- Bumped the Android/macOS app package version to `0.2.7+7`.

## [0.2.6] - 2026-04-28
### Fixed
- Latest-release OTA app-check now waits for BLE command/OTA transport again
  after downloading firmware, so reconnect churn during the GitHub download
  cannot turn into a false `missing_command_char` upload failure.
- Bumped the Android/macOS app package version to `0.2.6+6`.

## [0.2.5] - 2026-04-28
### Fixed
- Delayed the automated latest-release OTA upload check until the app has a
  fully bound BLE command characteristic and OTA characteristic, avoiding false
  `missing_command_char` failures during reconnect/service discovery.
- Bumped the Android/macOS app package version to `0.2.5+5`.

## [0.2.4] - 2026-04-28
### Fixed
- Deferred BLE reconnect/scan teardown while Android is actively uploading OTA
  firmware, preventing stale peer disconnects from interrupting the one-button
  GitHub firmware update path.
- Updated `nh02` app-check helpers so `--ota-latest-release` proves the public
  GitHub Release path without requiring a temporary local manifest.
- Bumped the Android/macOS app package version to `0.2.4+4` so installed phone
  builds can be identified without relying only on APK hashes.

## [0.2.3] - 2026-04-28
### Changed
- Simplified the Android ESP32 firmware update UI to two operator paths:
  selecting a local `firmware.bin` file on the phone or installing the latest
  firmware from the GitHub Release button.
- Removed operator-facing firmware URL/SHA fields and app-check controls from
  the Settings screen; URL/SHA OTA remains only as hidden bench automation.

## [0.2.2] - 2026-04-28
### Changed
- Android GitHub Release APKs now require stable release signing secrets on
  tagged builds so phone-side APK updates keep the same certificate across
  releases.
- Branch and pull-request Android builds may still use debug signing fallback
  for CI coverage, but tagged `v*` releases fail instead of publishing an
  update-incompatible debug-signed APK.

## [0.2.1] - 2026-04-27
### Added
- Added a standard `nh02` phone BLE OTA deploy wrapper (`tools/hw/nh02/deploy.sh`) that builds firmware and the release APK, installs the exact APK, uploads firmware through the phone, and waits for post-update telemetry recovery.
- Added release-app telemetry parsing for the previous v3 live frame so a newly installed app can still bridge an already-deployed v3 firmware to the current v4 firmware over BLE OTA.

### Changed
- Standardized phone/BLE manual control on atomic `MANUAL_TARGET:<angleDeg>,<throttlePct>,<ttlMs>` and `MANUAL_OFF`.
- Manual entry now disables Anchor mode and uses a deadman TTL so app/controller loss cannot resume Anchor unexpectedly.
- Split steering setup into motor steps per revolution and gear ratio, with `StepSpr=200` and `StepGear=36` defaults for the current DRV8825 full-step hardware.
- Raised default stepper speed/acceleration for usable manual steering response.
- Improved `nh02` Android OTA runner logging with artifact hashes, app launch state, progress heartbeats, and early logcat context when OTA does not start.

### Removed
- Removed legacy split manual commands `MANUAL`, `MANUAL_DIR`, and `MANUAL_SPEED` from the accepted command surface.

## [0.2.0] - 2026-03-02
### Added
- Deterministic on-device HIL simulation loop (`SIM_LIST`, `SIM_RUN`, `SIM_STATUS`, `SIM_REPORT`, `SIM_ABORT`) with virtual clock and seeded PRNG.
- Extended built-in scenario pack from `S0..S9` to `S0..S19`, including random-current/noisy-GNSS profiles and hardware-failure emulation:
  - compass loss/restore
  - power loss/restore
  - display loss/restore
  - actuator derate windows
- Sticky simulation status badge on device UI (`SIM LIVE` during run, result banner after completion).
- Expanded HIL unit coverage, including required-failsafe scenarios and full default-scenario pass sweep.

### Changed
- BLE link handling hardened for CoreBluetooth (stable MTU/connection params, notify subscription tracking, queued command/log processing).
- HIL report generation now memory-bounded (event truncation + counters) and robust to long event streams.
- Scenario-specific control tuning for hard-current case (`S2`) using max-thrust override.
- `S9` policy aligned with safety intent: expected NaN-triggered failsafe is treated as pass.

### Fixed
- Firmware reboot under heavy `SIM_REPORT` payloads (`bad_alloc`/abort in report serialization path).
- Repeated GNSS jump-event storms after quality degradation windows.
- BLE write/notify instability under high traffic (`Resources are insufficient`, disconnect churn on repeated report pulls).

## [0.1.0] - 2026-03-01
### Removed
- Route subsystem from firmware, BLE protocol, and Flutter UI (`SET_ROUTE`, `START_ROUTE`, `STOP_ROUTE` and route pages).
- SD route logging commands and UI (`EXPORT_LOG`, `CLEAR_LOG`, log pages and related storage/service code).
- Phone heading emulation path (`EMU_COMPASS`, `SET_HEADING`) and compass calibration compatibility command (`CALIB_COMPASS`).

### Changed
- Heading source is now onboard BNO08x only; phone GPS fallback remains for position only.
- BLE/UI simplified to anchor hold, manual control, stepper tuning, compass offset, and core diagnostics.

## [0.1.5] - 2026-02-28
### Fixed
- Aligned BLE `SET_ANCHOR` command format in Flutter app with firmware protocol (`SET_ANCHOR:<lat>,<lon>`).
- Removed duplicate BLE stream subscriptions and unsafe global BLE disconnect behavior in the mobile app.
- Added PlatformIO native test config and expanded BLE command handler unit coverage.
- Updated protocol/docs links and command descriptions (`MANUAL_SPEED`, `EXPORT_LOG`, `CLEAR_LOG`).

## [0.1.4] - 2025-07-18
### Added
- Manual rudder and motor speed control via BLE commands and Flutter UI.

## [0.1.3] - 2025-07-18
### Added
- Support for the HC 160A S2 motor controller with dual direction pins.

## [0.1.2] - 2025-07-17
### Fixed
- Register BLE distance parameter after initialization so the mobile app receives the correct value

## [0.1.1] - 2025-07-17
### Added
- Persistent calibration for the HMC5883 compass stored in EEPROM

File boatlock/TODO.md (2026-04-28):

# TODO — BoatLock Product Readiness

Active backlog for powered bench and protected-water readiness. The detailed
plan lives in `docs/PRODUCT_READINESS_PLAN.md`.

## P0 — Before Powered Bench

- [x] Clear stale app telemetry on BLE disconnect and disable map controls from stale `boatData`.
- [x] Split app anchor flow into explicit save-anchor and enable-anchor actions.
- [x] Add anchor enable preflight checklist: link, saved anchor, hardware GNSS, fresh heading, safety latch, motor readiness, STOP.
- [x] Add a normal `ANCHOR_OFF` UI action separate from emergency STOP.
- [x] Surface command send failures from map anchor actions.
- [x] Fix manual sheet wording: red `STOP` must either send real emergency `STOP` or be renamed to manual off.
- [x] Verify/fix that phone GPS fallback cannot update GPS-to-compass correction used by control heading.
- [x] Classify BLE commands into release/dev surfaces and gate dev paths from normal water UI.
- [x] Add explicit release/acceptance PlatformIO profiles and `nh02` flash-wrapper profile selection.
- [x] Implement firmware-side release/dev/HIL command enforcement through those profiles while keeping `SIM_*` available as a safe release-mode simulation path.
- [x] Remove confirmation from the app emergency STOP button: it must send `STOP` immediately, and the button should be visually separated to the left of normal controls.
- [ ] Identify the exact brushed/collector motor driver with `docs/BRUSHED_MOTOR_DRIVER_INTAKE.md` and update firmware/docs if it is not the current `PWM+DIR1+DIR2` path.
- [ ] Complete the DRV8825/Vanchor steering intake with current limit, enable/sleep/reset wiring, direction proof, and powered STOP behavior.
- [x] Build a no-load motor output acceptance checklist for `PWM=7`, `DIR=5/10`, boot, STOP, HOLD, reconnect, anchor denial, SIM, and OTA begin.
- [x] Add powered-bench wiring requirements: current-limited supply, fuse/breaker, physical kill path, polarity proof, strain relief, and thermal check.
- [ ] Update README wiring diagrams/photos from real hardware.

## P1 — Before First Protected-Water Test

- [x] Add a first-class readiness panel in the app with link age, GNSS/heading freshness, anchor gate, failsafe, manual lease, and motor readiness.
- [x] Add fixed 1.5 m anchor jog controls to the normal app UI.
- [x] Show distance and bearing to anchor as primary telemetry.
- [x] Add battery/power/current visibility or a required external measurement step in water-test logs.
- [x] Add track/history around anchor events for post-run review.
- [x] Add `MapPage` tests for disconnect, preflight, command failure, STOP, and manual-off behavior.
- [x] Remove or branch off leftover non-target surfaces: `BOATLOCK_BOARD_JC4832W535`, route UI labels, and unused `ReacqStrat`.
- [x] Add and pass the local pre-powered validation runner.
- [ ] Run `nh02`, Android, and no-load output validation before mounting powered hardware.

## P2 — Simulation And Product Polish

- [x] Normalize `tools/sim/research/environment_inputs.*` into simulator scenario data.
- [x] Add current, wind/gust, wave-induced forcing, current direction swing, and rocking metrics to simulator scenarios.
- [x] Add scenario provenance/confidence fields to normalized sim schema and reports.
- [x] Add loaded boat mass plus drag/windage parameters to scenario data and the world model.
- [x] Add yaw moment/heading inertia so environmental forcing can rotate the hull, not only translate it.
- [x] Add river/reservoir wake and short steep chop events.
- [ ] Model sensor-frame rocking effects on BNO08x/GNSS samples, not only hull-rocking metrics.
- [ ] Calibrate simulator profiles from hardware/current-voltage logs after powered bench data exists.
- [x] Add brushed motor, battery sag/current limit, thermal derate, and driver deadband to simulation.
- [x] Add steering backlash/jam/wrong-zero scenarios.
- [x] Add RF/Russian water-body scenarios: Oka normal, Volga spring flow, Rybinsk fetch, Ladoga storm abort, Baltic/Gulf drift.
- [x] Add production-path tests or simulation around `RuntimeMotion/MotorControl/StepperControl`.
- [ ] Add heading-hold as a separate operator flow after safe anchor hold is proven.
- [x] Design explicit multi-client control ownership before accepting a future BLE remote as a second controller.
- [ ] Implement and validate per-client control ownership before enabling a future BLE remote as a second controller.

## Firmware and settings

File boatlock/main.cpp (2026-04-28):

#include <Arduino.h>
#include <TinyGPSPlus.h>
#include <HardwareSerial.h>
#include <EEPROM.h>
#include <AccelStepper.h>
#include <math.h>
#include <strings.h>
#include <freertos/FreeRTOS.h>
#include <freertos/task.h>

#include "Settings.h"
#include "Logger.h"
#include "AnchorControl.h"
#include "MotorControl.h"
#include "StepperControl.h"
#include "display.h"
#include "BNO08xCompass.h"
#include "DriftMonitor.h"
#include "AnchorSupervisor.h"
#include "AnchorDiagnostics.h"
#include "GnssQualityGate.h"
#include "AnchorReasons.h"
#include "RuntimeButtons.h"
#include "RuntimeBleParams.h"
#include "RuntimeAnchorNudge.h"
#include "RuntimeAnchorGate.h"
#include "RuntimeCompassHealth.h"
#include "RuntimeCompassRetry.h"
#include "ManualControl.h"
#include "RuntimeControl.h"
#include "RuntimeControlInputBuilder.h"
#include "RuntimeGnss.h"
#include "RuntimeGpsUart.h"
#include "RuntimeMotion.h"
#include "RuntimeSimCommand.h"
#include "RuntimeSimExecution.h"
#include "RuntimeSimLog.h"
#include "RuntimeSimBadge.h"
#include "RuntimeStatus.h"
#include "RuntimeSupervisorPolicy.h"
#include "RuntimeTelemetryCadence.h"
#include "RuntimeUiSnapshot.h"
#include "BleOtaUpdate.h"
#include "HilSimRunner.h"
#include "BleCommandHandler.h"
#include "BLEBoatLock.h"
#include "SdCardLogger.h"

Settings settings;
constexpr size_t EEPROM_SIZE =
    Settings::EEPROM_ADDR + Settings::STORED_BYTES;

BLEBoatLock bleBoatLock;
BleOtaUpdate bleOta;
bool bleStarted = false;

namespace cfg {
constexpr char kFirmwareVersion[] = "0.2.7";

constexpr int kStepperStepPin = 6;
constexpr int kStepperDirPin = 16;
constexpr int kGpsRxPin = 17;
constexpr int kGpsTxPin = 18;
constexpr int kCompassRxPin = 12;
constexpr int kCompassTxPin = 11;
constexpr int kCompassResetPin = 13;
#if BOATLOCK_COMPASS_SH2_UART
constexpr uint32_t kCompassBaud = 3000000;
#else
constexpr uint32_t kCompassBaud = 115200;
#endif
constexpr int kMotorPwmPin = 7;
constexpr int kMotorDirPin1 = 8;
constexpr int kMotorDirPin2 = 10;
constexpr int kBootPin = 0;
constexpr int kStopButtonPin = 15;

constexpr int kPwmFreq = 5000;
constexpr int kPwmResolution = 8;
constexpr int kPwmChannel = 0;

constexpr int kMaxGpsFilterWindow = 20;
constexpr unsigned long kBleNotifyIntervalMs = 1000;
constexpr unsigned long kUiRefreshIntervalMs = 120;
constexpr unsigned long kCompassReadIntervalMs = 50;
constexpr unsigned long kCompassFirstEventTimeoutMs = 3000;
constexpr unsigned long kCompassStaleEventMs = 750;
constexpr unsigned long kBootSaveHoldMs = 1500;
constexpr unsigned long kCompassRetryIntervalMs = 5000;
constexpr unsigned long kGpsNoDataWarnMs = 6000;
constexpr unsigned long kGpsUartStaleRestartMs = 6000;
constexpr unsigned long kGpsUartRestartCooldownMs = 4000;
constexpr unsigned long kSimResultBannerMs = 15000;
constexpr unsigned long kSdTelemetryIntervalMs = 200;
} // namespace cfg

HardwareSerial gpsSerial(1);
HardwareSerial compassSerial(2);
TinyGPSPlus gps;
StepperControl stepperControl(cfg::kStepperStepPin, cfg::kStepperDirPin);

BNO08xCompass compass;
AnchorControl anchor;
MotorControl motor;
DriftMonitor driftMonitor;
AnchorSupervisor anchorSupervisor;
AnchorDiagnostics anchorDiagnostics;

bool compassReady = false;
unsigned long compassReadySinceMs = 0;
bool compassHeadingEventsReadyLogged = false;
float fallbackHeading = 0.0f;
float fallbackBearing = 0.0f;
enum class FixTypeSource : uint8_t {
  NONE = 0,
  NMEA_GSA = 1,
  UBX = 2,
};
FixTypeSource fixTypeSource = FixTypeSource::NONE;
bool minFixTypeIgnoredLogged = false;
unsigned long lastLoopMs = 0;
unsigned long lastSdTelemetryMs = 0;
ManualControl manualControl;
hilsim::HilSimManager hilSim;
unsigned long simLastWallMs = 0;
RuntimeGnss runtimeGnss;
RuntimeMotion runtimeMotion(settings, stepperControl, motor, driftMonitor);

bool headingAvailable() {
  return compassReady && compass.lastHeadingEventAgeMs(millis()) <= cfg::kCompassStaleEventMs;
}

void setPhoneGpsFix(float lat, float lon, float speedKmh, int satellites);
void captureStepperBowZero();
bool canEnableAnchorNow();
bool hasAnchorPoint();
void stopAllMotionNow();
void noteControlActivityNow();
bool nudgeAnchorCardinal(const char* dir);
bool nudgeAnchorBearing(float bearingDeg);
const char* currentGnssFailReason();
AnchorDeniedReason currentAnchorEnableDeniedReason();
void applySupervisorDecision(const AnchorSupervisor::Decision& decision);
void setLastAnchorDeniedReason(AnchorDeniedReason reason);
void setLastFailsafeReason(FailsafeReason reason);
void clearSafeHold();
const char* currentAnchorDeniedReason();
const char* currentFailsafeReason();
AnchorDeniedReason currentGnssDeniedReason();
bool preprocessBleCommand(const std::string& incoming, std::string* effective);
bool handleSimCommand(const std::string& command);

namespace {
TaskHandle_t stepperTaskHandle = nullptr;
bool controlGpsAvailable();

unsigned long lastGpsDebugMs = 0;
unsigned long lastGpsJumpRejectLogMs = 0;
RuntimeButtons runtimeButtons;
RuntimeTelemetryCadence telemetryCadence;
RuntimeGpsUart gpsUart;
RuntimeCompassRetry compassRetry;
unsigned long bootMs = 0;
RuntimeSimBadge runtimeSimBadge;

const char* fixTypeSourceString(FixTypeSource src) {
  switch (src) {
    case FixTypeSource::NMEA_GSA:
      return "NMEA_GSA";
    case FixTypeSource::UBX:
      return "UBX";
    case FixTypeSource::NONE:
    default:
      return "NONE";
  }
}

bool anchorPointConfigured() {
  return AnchorControl::validAnchorPoint(anchor.anchorLat, anchor.anchorLon);
}

bool gpsQualityGoodForAnchorOn() {
  return runtimeGnss.gpsQualityGoodForAnchorOn(settings);
}

int gnssQualityLevel() {
  return runtimeGnss.gnssQualityLevel(settings);
}

void setSafetyReason(const char* reason) {
  runtimeMotion.setSafetyReason(reason, millis());
}

std::string activeSafetyReason(unsigned long now) {
  return runtimeMotion.activeSafetyReason(now);
}

RuntimeStatusInput currentRuntimeStatusInput(unsigned long now, std::string* safetyReason) {
  RuntimeStatusInput input;
  if (hilSim.isRunning()) {
    hilsim::HilScenarioRunner::LiveTelemetry live;
    const bool liveOk = hilSim.liveTelemetry(&live);
    input.gpsUnavailable = !(liveOk && live.gnss.valid);
    input.gnssWeak = false;
    input.gnssWeakReason = nullptr;
    input.headingAvailable = liveOk && live.heading.valid;
    input.driftFail = false;
    input.driftAlert = false;
    input.anchorActive = false;
    input.anchorDeniedReason = nullptr;
    input.failsafeReason = nullptr;
    input.holdMode = false;
    if (safetyReason) {
      safetyReason->clear();
      input.safetyReason = safetyReason->c_str();
    }
    return input;
  }
  input.gpsUnavailable = !gps.location.isValid() && !runtimeGnss.fix();
  input.gnssWeak = !input.gpsUnavailable && !gpsQualityGoodForAnchorOn();
  input.gnssWeakReason = input.gnssWeak ? currentGnssFailReason() : nullptr;
  input.headingAvailable = headingAvailable();
  input.driftFail = runtimeMotion.driftFailActive();
  input.driftAlert = runtimeMotion.driftAlertActive();
  input.anchorActive = settings.get("AnchorEnabled") == 1;
  input.anchorDeniedReason =
      (!input.anchorActive && runtimeMotion.lastAnchorDeniedReason() != AnchorDeniedReason::NONE)
          ? currentAnchorDeniedReason()
          : nullptr;
  input.failsafeReason =
      (runtimeMotion.lastFailsafeReason() != FailsafeReason::NONE) ? currentFailsafeReason()
                                                                   : nullptr;
  if (safetyReason) {
    *safetyReason = activeSafetyReason(now);
    input.safetyReason = safetyReason->c_str();
  }
  input.holdMode = runtimeMotion.safeHoldActive();
  return input;
}

std::string buildCurrentStatusReasons(unsigned long now) {
  std::string safetyReason;
  const RuntimeStatusInput input = currentRuntimeStatusInput(now, &safetyReason);
  return buildRuntimeStatusReasons(input);
}

RuntimeStatusSnapshot buildCurrentStatusSnapshot(unsigned long now) {
  std::string safetyReason;
  const RuntimeStatusInput input = currentRuntimeStatusInput(now, &safetyReason);
  return buildRuntimeStatusSnapshot(input);
}

float normalizeDiffDeg(float targetDeg, float currentDeg) {
  return RuntimeGnss::normalizeDiffDeg(targetDeg, currentDeg);
}

float normalize360Deg(float deg) {
  return RuntimeGnss::normalize360Deg(deg);
}

float normalize180Deg(float deg) {
  return RuntimeGnss::normalize180Deg(deg);
}

CoreMode currentCoreMode();

const char* currentModeLabel() {
  return coreModeLabel(currentCoreMode());
}

CoreMode currentCoreMode() {
  return resolveCoreMode(hilSim.isRunning(),
                         manualControl.active(),
                         settings.get("AnchorEnabled") == 1,
                         runtimeMotion.safeHoldActive());
}

float currentHeadingValue() {
  return runtimeGnss.currentHeadingValue(headingAvailable(), compass.getAzimuth(), millis());
}

bool controlGpsAvailable() {
  return runtimeGnss.controlGpsAvailable();
}

void stepperTask(void*) {
  for (;;) {
    stepperControl.run();
    vTaskDelay(1);
  }
}

void registerBleParams() {
  RuntimeBleParamContext context{
      bleBoatLock,
      settings,
      runtimeGnss,
      runtimeMotion,
      anchor,
      motor,
      driftMonitor,
      compass,
      hilSim,
      handleBleCommand,
      []() { return headingAvailable(); },
      []() { return currentHeadingValue(); },
      []() { return currentModeLabel(); },
      []() { return gnssQualityLevel(); },
      []() { return buildCurrentStatusSnapshot(millis()); },
      []() { return fixTypeSourceString(fixTypeSource); },
  };
  registerRuntimeBleParams(context);
}

void startBleRuntime() {
  if (bleStarted) {
    return;
  }
  bleBoatLock.begin();
  bleStarted = true;
}

void serviceBleRuntime() {
  if (bleStarted) {
    bleBoatLock.loop();
  }
}

void updateGpsFromSerial() {
  size_t bytesRead = 0;
  while (gpsSerial.available()) {
    gps.encode(gpsSerial.read());
    ++bytesRead;
  }

  const unsigned long now = millis();
  RuntimeGpsUartConfig uartConfig;
  uartConfig.noDataWarnMs = cfg::kGpsNoDataWarnMs;
  uartConfig.staleRestartMs = cfg::kGpsUartStaleRestartMs;
  uartConfig.restartCooldownMs = cfg::kGpsUartRestartCooldownMs;
  const RuntimeGpsUartActions uartActions = gpsUart.update(bytesRead, now, uartConfig);

  if (uartActions.firstDataSeen) {
    logMessage("[GPS] UART data detected RX=%d TX=%d baud=9600\n",
               cfg::kGpsRxPin,
               cfg::kGpsTxPin);
  }

  if (uartActions.warnNoData) {
    logMessage("[GPS] no UART bytes on RX=%d (check wiring/baud/power)\n", cfg::kGpsRxPin);
  }

  if (uartActions.warnStale) {
    logMessage("[GPS] UART stream stale (%lu ms), restarting serial\n", uartActions.staleAgeMs);
  }

  if (uartActions.restartSerial) {
    gpsSerial.end();
    delay(20);
    gpsSerial.begin(9600, SERIAL_8N1, cfg::kGpsRxPin, cfg::kGpsTxPin);
    gps = TinyGPSPlus();
    logMessage("[GPS] UART restarted RX=%d TX=%d baud=9600\n", cfg::kGpsRxPin, cfg::kGpsTxPin);
  }

  if (settings.get("DebugGps") == 1 && millis() - lastGpsDebugMs >= 1000) {
    Serial.printf("[GPS] bytes=%lu valid=%d fix=%d sats=%d hdop=%.2f age=%lu\n",
                  gps.charsProcessed(),
                  gps.location.isValid(),
                  runtimeGnss.fix(),
                  gps.satellites.value(),
                  gps.hdop.value() * 0.01f,
                  gps.location.age());
    lastGpsDebugMs = millis();
  }

  const unsigned long maxGpsAgeMs =
      static_cast<unsigned long>(constrain(settings.get("MaxGpsAgeMs"), 300.0f, 20000.0f));
  const bool hardwareFix = gps.location.isValid() && gps.location.age() < maxGpsAgeMs;
  if (hardwareFix) {
    RuntimeGnss::HardwareFixInput fix;
    fix.lat = gps.location.lat();
    fix.lon = gps.location.lng();
    fix.speedKmh = gps.speed.kmph();
    fix.satellites = max(0, (int)gps.satellites.value());
    fix.hdop = gps.hdop.isValid() ? (gps.hdop.value() * 0.01f) : NAN;
    fix.ageMs = gps.location.age();
    const bool headingOk = headingAvailable();
    const RuntimeGnss::ApplyResult result = runtimeGnss.applyHardwareFix(
        fix, settings, headingOk, compass.getAzimuth(), now);
    if (result == RuntimeGnss::ApplyResult::JUMP_REJECTED &&
        now - lastGpsJumpRejectLogMs >= 1000UL) {
      logMessage("[EVENT] GPS_JUMP_REJECTED jump=%.2f max=%.2f\n",
                 runtimeGnss.currentPosJumpM(),
                 constrain(settings.get("MaxPosJumpM"), 1.0f, 200.0f));
      lastGpsJumpRejectLogMs = now;
    }
    return;
  }

  if (runtimeGnss.applyPhoneFallback(headingAvailable(), compass.getAzimuth(), now)) {
    return;
  }

  runtimeGnss.clearFix();
}

void handleBootButton() {
  const bool pressed = digitalRead(cfg::kBootPin) == LOW;
  const unsigned long now = millis();
  const RuntimeButtonAction action = runtimeButtons.updateBoot(
      pressed, now, cfg::kBootSaveHoldMs, controlGpsAvailable(), currentGnssDeniedReason());
  if (action.type == RuntimeButtonActionType::NONE) {
    return;
  }

  if (action.type == RuntimeButtonActionType::SAVE_ANCHOR_POINT) {
    if (!anchor.saveAnchor(
            runtimeGnss.lastLat(), runtimeGnss.lastLon(), currentHeadingValue(), false)) {
      setLastAnchorDeniedReason(AnchorDeniedReason::INTERNAL_ERROR);
      logMessage("[EVENT] ANCHOR_DENIED reason=GPS_INVALID source=BOOT_BUTTON\n");
      return;
    }
    setLastAnchorDeniedReason(AnchorDeniedReason::NONE);
    setLastFailsafeReason(FailsafeReason::NONE);
    logMessage("[EVENT] ANCHOR_POINT_SAVED source=BOOT_BUTTON\n");
    logMessage("[ANCHOR] point saved from BOOT button; anchor remains OFF\n");
    return;
  }

  if (action.type == RuntimeButtonActionType::DENY_ANCHOR_POINT) {
    setLastAnchorDeniedReason(action.deniedReason);
    logMessage("[EVENT] ANCHOR_DENIED reason=%s source=BOOT_BUTTON\n",
               currentGnssFailReason());
    logMessage("[ANCHOR] BOOT save rejected (control GNSS unavailable)\n");
  }
}

void handleStopButton() {
  const bool pressed = digitalRead(cfg::kStopButtonPin) == LOW;
  const unsigned long now = millis();
  const RuntimeButtonAction action =
      runtimeButtons.updateStop(pressed, now);
  if (action.type == RuntimeButtonActionType::EMERGENCY_STOP) {
    setLastFailsafeReason(FailsafeReason::STOP_CMD);
    stopAllMotionNow();
    logMessage("[STOP] hardware stop button pressed (GPIO%d)\n", cfg::kStopButtonPin);
    return;
  }
}

void updateDistanceAndBearing() {
  runtimeGnss.updateDistanceAndBearing(manualControl.active(),
                                       settings.get("AnchorEnabled") == 1,
                                       settings.get("HoldHeading") == 1,
                                       anchor.anchorLat,
                                       anchor.anchorLon,
                                       anchor.anchorHeading,
                                       millis());
}

void updateDriftState(unsigned long now) {
  runtimeMotion.updateDriftState(now, currentCoreMode(), runtimeGnss.fix(), runtimeGnss.distanceM());
}

void applyMotionControl(const RuntimeControlInput& input) {
  runtimeMotion.applyControl(input);
}
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
void loop() {
  const unsigned long wallNowMs = millis();
  const unsigned long wallDtMs =
      (simLastWallMs == 0 || wallNowMs < simLastWallMs) ? 0 : (wallNowMs - simLastWallMs);
  simLastWallMs = wallNowMs;
  hilSim.loop(wallDtMs);
  serviceBleRuntime();
  bleOta.loop();

  const bool simRunningNow = hilSim.isRunning();
  if (!simRunningNow) {
    updateGpsFromSerial();
    handleBootButton();
  }
  handleStopButton();

  const unsigned long now = millis();
  if (!simRunningNow &&
      compassRetry.shouldRetry(compassReady, now, cfg::kCompassRetryIntervalMs)) {
    const bool resetPulse = compass.hardwareReset();
    compassReady =
        compass.begin(compassSerial, cfg::kCompassRxPin, cfg::kCompassTxPin, cfg::kCompassBaud);
    compassReadySinceMs = compassReady ? now : 0;
    compassHeadingEventsReadyLogged = false;
    logMessage("[COMPASS] retry ready=%d source=%s rx=%d tx=%d baud=%lu reset=%d\n",
               (int)compassReady,
               compass.sourceName(),
               compass.rxPin(),
               compass.txPin(),
               (unsigned long)compass.baud(),
               resetPulse ? 1 : 0);
    if (compassReady) {
      compass.loadCalibrationFromSettings();
      logMessage("[COMPASS] heading offset=%.1f\n", compass.getHeadingOffsetDeg());
    }
  }

  if (!simRunningNow && compassReady &&
      telemetryCadence.shouldPollCompass(now, cfg::kCompassReadIntervalMs)) {
    const BNO08xCompassReadResult compassRead = compass.read();
    if (compassRead.headingEvent && !compassHeadingEventsReadyLogged) {
      compassHeadingEventsReadyLogged = true;
      logMessage("[COMPASS] heading events ready age=%lu\n", compass.lastHeadingEventAgeMs(millis()));
    }
  }

  if (!simRunningNow && compassReady) {
    const unsigned long compassHealthNow = millis();
    RuntimeCompassHealthInput compassHealth;
    compassHealth.compassReady = compassReady;
    compassHealth.nowMs = compassHealthNow;
    compassHealth.readySinceMs = compassReadySinceMs;
    compassHealth.lastHeadingEventAgeMs = compass.lastHeadingEventAgeMs(compassHealthNow);
    compassHealth.firstEventTimeoutMs = cfg::kCompassFirstEventTimeoutMs;
    compassHealth.staleEventMs = cfg::kCompassStaleEventMs;
    const RuntimeCompassLossReason lossReason = runtimeCompassLossReason(compassHealth);
    if (lossReason != RuntimeCompassLossReason::NONE) {
      logMessage("[COMPASS] lost reason=%s age=%lu\n",
                 runtimeCompassLossReasonString(lossReason),
                 compassHealth.lastHeadingEventAgeMs);
      compassReady = false;
      compassReadySinceMs = 0;
      compassHeadingEventsReadyLogged = false;
    }
  }

  manualControl.update(now);
  updateDistanceAndBearing();
  const unsigned long loopDtMs = (lastLoopMs == 0 || now < lastLoopMs) ? 0 : (now - lastLoopMs);
  lastLoopMs = now;
  updateDriftState(now);

  const CoreMode mode = currentCoreMode();
  const bool anchorActive = coreModeUsesAnchorControl(mode);
  const bool gpsQualityOk = gpsQualityGoodForAnchorOn();
  const bool bleConnected = (bleBoatLock.bleStatus == BLEBoatLock::CONNECTED);
  const AnchorSupervisor::Config supCfg = buildRuntimeSupervisorConfig(settings);
  const AnchorSupervisor::Input supIn = buildRuntimeSupervisorInput(
      now,
      anchorActive,
      gpsQualityOk,
      bleConnected,
      controlGpsAvailable() && headingAvailable(),
      (!isfinite(runtimeGnss.distanceM()) || !isfinite(runtimeGnss.bearingDeg())),
      runtimeMotion.driftFailActive(),
      loopDtMs,
      motor.pwmPercent());
  applySupervisorDecision(anchorSupervisor.update(supCfg, supIn));

  const CoreMode controlMode = currentCoreMode();
  const float heading = currentHeadingValue();
  const bool anchorBearingAvailable =
      runtimeGnss.anchorBearingAvailable(coreModeUsesAnchorControl(controlMode),
                                         settings.get("HoldHeading") == 1,
                                         now);
  const bool headingOk = headingAvailable();
  const RuntimeControlState controlState = buildRuntimeControlState(
      now,
      controlMode,
      manualControl.angleDeg(),
      manualControl.motorPwm(),
      controlGpsAvailable(),
      headingOk,
      heading,
      anchorBearingAvailable,
      runtimeGnss.bearingDeg(),
      headingOk,
      headingOk ? compass.getRvAccuracyDeg() : NAN,
      headingOk ? compass.getHeadingQuality() : 0,
      runtimeGnss.distanceM());

  const char* stickyBadge = runtimeSimBadge.update(
      simRunningNow, hilSim.currentScenarioId(), hilSim.lastPass(), now, cfg::kSimResultBannerMs);

  applyMotionControl(controlState.input);
  const AnchorDiagnostics::Events diag = anchorDiagnostics.update(
      now,
      controlState.autoControlActive,
      runtimeGnss.fix(),
      controlState.hasHeading,
      runtimeMotion.driftAlertActive(),
      motor.pwmPercent(),
      MotorControl::AUTO_MAX_PWM_PCT);
  if (diag.driftAlert) {
    logMessage("[EVENT] DRIFT_ALERT dist=%.2f\n", runtimeGnss.distanceM());
  }
  if (diag.controlSaturated) {
    logMessage("[EVENT] CONTROL_SATURATED pwm=%d\n", motor.pwmPercent());
  }
  if (diag.sensorTimeout) {
    logMessage("[EVENT] SENSOR_TIMEOUT\n");
  }
  publishBleAndUi(
      now, controlState.hasHeading, controlState.hasBearing, controlState.headingDeg, controlState.diffDeg, stickyBadge);
  enqueueSdTelemetry(now, controlState);
  sdCardLogger.service(now);

  serviceBleRuntime();
}

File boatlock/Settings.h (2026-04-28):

#pragma once
#include <math.h>
#include <nvs.h>
#include <stddef.h>
#include <string.h>
#include <stdint.h>
#include "Logger.h"

enum SettingType { TYPE_INT, TYPE_FLOAT, TYPE_BOOL };

struct SettingEntry {
    const char* key;
    const char* description;
    SettingType type;
    float value;
    float defaultValue;
    float minValue, maxValue, step;
    const char* unit;
    bool visibleInMenu;
};

const SettingEntry defaultEntries[] = {
    // GNSS quality gate
    {"MinFixType", "Min fix type",      TYPE_INT,   3.0,  3.0,   2.0,   3.0,    1.0, "", false},
    {"MinSats",    "Min satellites",    TYPE_INT,   10.0,  10.0,   3.0,  20.0,    1.0, "", true},
    {"MaxHdop",    "Max HDOP",          TYPE_FLOAT, 1.8,  1.8,   0.5,  10.0,    0.1, "", true},
    {"MaxGpsAgeMs","Max GPS age",       TYPE_INT,   1500, 1500,  300, 20000,  100.0, "ms", false},
    {"MaxPosJumpM","Max GPS jump",      TYPE_FLOAT, 8.0, 8.0,  1.0, 200.0,    0.5, "m", false},
    {"MinStatSpd", "Min stationary spd",TYPE_FLOAT, 0.25, 0.25,  0.05, 2.0,    0.01, "m/s", false},
    {"SpdSanity",  "Speed sanity",      TYPE_INT,   0.0,  0.0,   0.0,   1.0,    1.0, "", false},
    {"MaxSpdMps",  "Max speed sanity",  TYPE_FLOAT, 25.0, 25.0,  1.0,  60.0,    0.5, "m/s", false},
    {"MaxAccMps2", "Max accel sanity",  TYPE_FLOAT, 6.0,  6.0,   0.5,  20.0,    0.1, "m/s2", false},
    {"ReqSent",    "Required sentences",TYPE_INT,   0.0,  0.0,   0.0,  20.0,    1.0, "", false},

    // Anchor control
    {"HoldRadius", "Hold radius",       TYPE_FLOAT, 3.0,  3.0,   0.5,  20.0,    0.1, "m", true},
    {"DeadbandM",  "Anchor deadband",   TYPE_FLOAT, 2.2,  2.2,   0.2,  10.0,    0.1, "m", true},
    {"MaxThrustA", "Max thrust anchor", TYPE_INT,   45.0, 45.0,  10.0, 100.0,   1.0, "%", true},
    {"ThrRampA",   "Thrust ramp anchor",TYPE_FLOAT, 20.0, 20.0,  1.0, 100.0,    1.0, "%/s", true},
    {"MaxTurnRt",  "Max turn rate",     TYPE_FLOAT, 120.0,120.0, 30.0, 720.0,   1.0, "deg/s", false},

    // Safety supervisor
    {"CommToutMs", "Comm timeout",      TYPE_INT,   4000, 4000,  3000, 60000,  100.0, "ms", false},
    {"CtrlLoopMs", "Control loop tout", TYPE_INT,   200,  200,   100, 10000,   10.0, "ms", false},
    {"SensorTout", "Sensor timeout",    TYPE_INT,   1500, 1500,  300, 30000,  100.0, "ms", false},
    // UX / events
    {"GpsWeakHys", "GPS weak hysteresis", TYPE_FLOAT, 1.5, 1.5, 0.5, 60.0, 0.5, "s", false},
    {"EventRateMs","Event rate limit",  TYPE_INT,   1000, 1000, 100, 10000, 100.0, "ms", false},

    {"DriftAlert","Drift alert",        TYPE_FLOAT, 6.0,  6.0,   2.0, 200.0,  0.5, "m", true},
    {"DriftFail", "Drift fail",         TYPE_FLOAT, 12.0, 12.0,  5.0, 500.0,  1.0, "m", true},
    {"AngTol",    "Angle tolerance",    TYPE_FLOAT, 3.0,  3.0,   0.1,  180.0, 1.0, "deg", true},
    {"ScreenBr",  "Screen brightness",  TYPE_INT,   128.0,128.0, 0,    255,    1, "", true},
    {"Encoder0",  "Encoder zero",       TYPE_INT,   0,    0,     0,   16384,   1, "", false},
    {"USAngle",   "US angle",           TYPE_FLOAT, 30.0, 30.0,  0.0,  90.0,   1.0, "deg", false},
    {"USThresh",  "US threshold",       TYPE_FLOAT, 1.5,  1.5,   0.1,  6.0,    0.1, "m", false},
    {"GPS_TYPE",  "GPS model",          TYPE_INT,   0, 0, 0, 4, 1, "", false},
    {"IMU_TYPE",  "IMU model",          TYPE_INT,   1, 1, 0, 4, 1, "", false},
    {"GpsFWin",   "GPS filter window",  TYPE_INT,   5,    5,     1,   20,    1, "", false},
    {"DebugGps",  "Debug GPS serial",   TYPE_INT,   0,    0,     0,   1,     1, "", true},
    {"AnchorEnabled", "Enable anchor",     TYPE_INT,   0, 0, 0, 1, 1, "", false},
    {"AnchorLat",     "Anchor latitude",   TYPE_FLOAT, 0.0, 0.0, -90.0, 90.0,   0.000001, "", false},
    {"AnchorLon",     "Anchor longitude",  TYPE_FLOAT, 0.0, 0.0,-180.0, 180.0, 0.000001, "", false},
    {"AnchorHead",    "Anchor heading",    TYPE_FLOAT, 0.0, 0.0,   0.0, 360.0, 1.0, "deg", false},
    {"HoldHeading",   "Hold heading",      TYPE_INT,   0, 0, 0, 1, 1, "", true},
    {"MagOffX",      "Compass offset X",  TYPE_FLOAT, 0.0, 0.0, -5000.0, 5000.0, 1.0, "", false},
    {"MagOffY",      "Compass offset Y",  TYPE_FLOAT, 0.0, 0.0, -5000.0, 5000.0, 1.0, "", false},
    {"MagOffZ",      "Compass offset Z",  TYPE_FLOAT, 0.0, 0.0, -5000.0, 5000.0, 1.0, "", false},
    {"MagScaleX",    "Compass scale X",   TYPE_FLOAT, 1.0, 1.0, 0.1, 5.0, 0.01, "", false},
    {"MagScaleY",    "Compass scale Y",   TYPE_FLOAT, 1.0, 1.0, 0.1, 5.0, 0.01, "", false},
    {"MagScaleZ",    "Compass scale Z",   TYPE_FLOAT, 1.0, 1.0, 0.1, 5.0, 0.01, "", false},
    {"StepMaxSpd",   "Stepper max speed", TYPE_FLOAT, 2400.0, 2400.0, 100.0, 4000.0, 10.0, "", true},
    {"StepAccel",    "Stepper accel",     TYPE_FLOAT, 2400.0, 2400.0,  50.0, 4000.0, 10.0, "", true},
    {"StepSpr",      "Motor steps/rev",   TYPE_INT,   200, 200,  50,  6400, 1, "", true},
    {"StepGear",     "Stepper gear ratio",TYPE_FLOAT, 36.0, 36.0,  1.0,  100.0, 0.1, "", true},
};
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

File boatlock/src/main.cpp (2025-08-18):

#include <Arduino.h>
#include <Wire.h>
#include <Adafruit_GFX.h>
#include <Adafruit_SSD1306.h>
#include <TinyGPSPlus.h>
#include <HardwareSerial.h>
#include <EEPROM.h>
#include <AccelStepper.h>
#include <math.h>
#include <freertos/FreeRTOS.h>
#include <freertos/task.h>
#include <SPI.h>
#include <SD.h>

#include "Settings.h"
#include "Logger.h"
Settings settings;
constexpr size_t EEPROM_SIZE = Settings::EEPROM_ADDR + sizeof(float) * count + sizeof(uint8_t);
#include "AnchorControl.h"
#include "MotorControl.h"
#include "StepperControl.h"

#include "BoatDisplay.h"
#include "HMC5883Compass.h"
#include "PathControl.h"
#include "BleCommandHandler.h"

#include "BLEBoatLock.h"
BLEBoatLock bleBoatLock;

File routeLog;
const char* ROUTE_LOG_PATH = "/route.csv";
bool sdReady = false;

#define SCREEN_WIDTH 128
#define SCREEN_HEIGHT 64
#define OLED_RESET    -1

Adafruit_SSD1306 display(SCREEN_WIDTH, SCREEN_HEIGHT, &Wire, OLED_RESET);
BoatDisplay boatDisplay(&display);

#define STEP_PIN 5
#define DIR_PIN 4
#define MOTOR_PWM_PIN 7
#define MOTOR_DIR_PIN1 6
#define MOTOR_DIR_PIN2 10
const int PWM_FREQ = 5000;
const int PWM_RESOLUTION = 8;
const int PWM_CHANNEL = 0;

HardwareSerial gpsSerial(1);
TinyGPSPlus gps;
StepperControl stepperControl(STEP_PIN, DIR_PIN);

TaskHandle_t stepperTaskHandle = nullptr;
void stepperTask(void*);

HMC5883Compass compass;
AnchorControl anchor;
MotorControl motor;
PathControl pathControl;
bool compassReady = false;

TaskHandle_t compassCalibTaskHandle = nullptr;

void compassCalibTask(void*);

#define BOOT_PIN 0

bool holding = false;
float targetAngle = 0;
float encoderAngle = 0;
unsigned long lastDraw = 0;
const unsigned long drawInterval = 100;
float dist = 0, bearing = 0;

float lastLat = 0, lastLon = 0;
bool gpsFix = false;
float emuHeading = 0;

const int MAX_GPS_FILTER = 20;
float latBuf[MAX_GPS_FILTER];
float lonBuf[MAX_GPS_FILTER];
int gpsBufCount = 0;
int gpsBufIndex = 0;
int gpsWindow = 5;
float gpsLatSum = 0, gpsLonSum = 0;

bool manualMode = false;
int manualDir = -1;
int manualSpeed = 0;

void drawDebug(const String &msg, int y = 48) {
  display.clearDisplay();
  display.setTextSize(1);
  display.setTextColor(SSD1306_WHITE);
  display.setCursor(0,  y);
  display.print("[D]");
  display.print(msg);
  display.display();
}

template<typename F>
std::function<std::string()> makeFloatParam(F valueFunc, const char* fmt) {
    return [valueFunc, fmt]() {
        char buf[20];
        snprintf(buf, sizeof(buf), fmt, valueFunc());
        return std::string(buf);
    };
}

void calibrateCompassAndSave() {
  if (!compassReady) return;
  drawDebug("Calibrating compass");
  compass.calibrate();
  drawDebug("Calib done");
}

void compassCalibTask(void*) {
  calibrateCompassAndSave();
  compassCalibTaskHandle = nullptr;
  vTaskDelete(nullptr);
}

void startCompassCalibration() {
  if (compassCalibTaskHandle == nullptr && compassReady) {
    xTaskCreatePinnedToCore(compassCalibTask, "compassCalib", 4096, nullptr, 1, &compassCalibTaskHandle, 1);
  }
}

void stepperTask(void*) {
  for(;;) {
    stepperControl.run();
    vTaskDelay(1);
  }
}

void setup() {
  Serial.begin(115200);
  logMessage("\n[BoatLock] ESP32 стартует! Версия прошивки: 0.1.2\n");

  Wire.begin(8, 9);
  compassReady = compass.init();

  pinMode(BOOT_PIN, INPUT_PULLUP);

  display.begin(SSD1306_SWITCHCAPVCC, 0x3C);
  gpsSerial.begin(9600, SERIAL_8N1, 17, 18);

  bleBoatLock.setCommandHandler(handleBleCommand);
  bleBoatLock.registerParam("lat", makeFloatParam([&](){
      return gpsFix ? lastLat : 0.0f;
  }, "%.6f"));
  bleBoatLock.registerParam("lon", makeFloatParam([&](){
      return gpsFix ? lastLon : 0.0f;
  }, "%.6f"));
  bleBoatLock.registerParam("heading",  makeFloatParam([&](){
      if (settings.get("EmuCompass")) return emuHeading;
      return compassReady ? (float)compass.getAzimuth() : 0.0f;
  }, "%.1f"));
  bleBoatLock.registerParam("anchorLat", makeFloatParam([&](){ return isnan(anchor.anchorLat) ? 0.0 : anchor.anchorLat;}, "%.6f"));
  bleBoatLock.registerParam("anchorLon", makeFloatParam([&](){ return isnan(anchor.anchorLon) ? 0.0 : anchor.anchorLon;}, "%.6f"));
  bleBoatLock.registerParam("anchorHead", makeFloatParam([&](){ return anchor.anchorHeading; }, "%.1f"));
  bleBoatLock.registerParam("holdHeading", makeFloatParam([&](){ return settings.get("HoldHeading"); }, "%.0f"));
  bleBoatLock.registerParam("emuCompass", makeFloatParam([&](){ return settings.get("EmuCompass"); }, "%.0f"));
  bleBoatLock.registerParam("routeIdx", makeFloatParam([&](){ return (float)pathControl.currentIndex; }, "%.0f"));
  bleBoatLock.registerParam("stepSpr", makeFloatParam([&](){ return settings.get("StepSpr"); }, "%.0f"));
  bleBoatLock.registerParam("stepMaxSpd", makeFloatParam([&](){ return settings.get("StepMaxSpd"); }, "%.0f"));
  bleBoatLock.registerParam("stepAccel", makeFloatParam([&](){ return settings.get("StepAccel"); }, "%.0f"));

  EEPROM.begin(EEPROM_SIZE);
  settings.load();
  gpsWindow = (int)settings.get("GpsFWin");
  compass.attachSettings(&settings);
  if (compassReady) {
    compass.loadCalibrationFromSettings();
  }
  anchor.attachSettings(&settings);
  anchor.loadAnchor();
  bleBoatLock.begin();
 
  sdReady = SD.begin();
  if (sdReady) {
    routeLog = SD.open(ROUTE_LOG_PATH, FILE_APPEND);
  }

  bleBoatLock.registerParam("distance", makeFloatParam([&](){ return dist; }, "%.2f"));
  bleBoatLock.registerParam("mode", [ & ](){
      if (manualMode) return std::string("MANUAL");
      if (pathControl.active) return std::string("ROUTE");
      if (settings.get("AnchorEnabled") == 1) return std::string("ANCHOR");
      return std::string("IDLE");
  });

  pinMode(BOOT_PIN, INPUT_PULLUP);
  motor.setupPWM(MOTOR_PWM_PIN, PWM_CHANNEL, PWM_FREQ, PWM_RESOLUTION);
  motor.setDirPins(MOTOR_DIR_PIN1, MOTOR_DIR_PIN2);
  motor.loadPIDfromSettings();
  stepperControl.attachSettings(&settings);
  stepperControl.loadFromSettings();

  xTaskCreatePinnedToCore(stepperTask, "stepper", 2048, nullptr, 1, &stepperTaskHandle, 1);
}
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

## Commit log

2025-06-16 Remove default README and sample files
2025-06-17 Add basic DRV8825 stepper support
2025-06-17 Improve motor control with time-based PID
2025-06-17 feat(ui): show map without BLE and track position
2025-06-18 Add compass calibration via BLE
2025-06-18 Run compass calibration in async task
2025-06-19 refactor stepper control
2025-06-19 Allow manual map scrolling and add recenter button
2025-06-19 Allow stepper operation without GPS fix
    [main.cpp]
2025-06-20 Replace flutter_compass with sensors_plus
2025-06-20 Add busy state and run method to StepperControl
2025-06-20 Add stepper settings and Flutter UI
2025-06-20 Run stepper in RTOS task
2025-06-21 commm encoder
2025-06-26 Switch to BNO085 compass
2025-06-26 Handle compass init failures
    [BleCommandHandler.h, main.cpp]
2025-07-06 Switch to Adafruit HMC5883 compass
2025-07-17 Persist compass calibration in EEPROM
2025-07-17 Fix distance BLE param
    [main.cpp]
2025-07-17 fix: correct stepper speed command parsing
    [BleCommandHandler.h]
2025-07-17 Fix stepper motor update logic
    [main.cpp]
2025-07-17 Add dual direction pin support
2025-07-17 Add PID motor control during anchor
2025-07-17 Stop stepper when entering manual mode
2025-08-14 Track status and display in Flutter
2025-08-14 Log route to SD and view track
2025-08-18 Stop stepper when GPS lost and limit steering checks
2025-12-17 Throttle PID EEPROM writes
2026-01-26 Restructure firmware as Arduino sketch
2026-01-26 Fix Arduino build errors
    [MotorControl.h]
2026-01-26 Document Arduino duplicate definition issue
2026-01-26 Update I2C pins and GPS status UI
2026-01-26 Skip compass init when device absent
2026-01-26 Update display layout and error metrics
    [display.cpp]
2026-01-26 Fix display layout sizing
    [display.cpp]
2026-01-26 Limit full redraws to avoid flicker
    [display.cpp]
2026-01-26 Redesign display layout for light dashboard
    [display.cpp]
2026-02-28 Refactor Arduino compatibility and update tests
2026-02-28 release: stabilize display pipeline and phone gps heading flow
    [BleCommandHandler.h, MotorControl.h, Settings.h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]
2026-03-01 Add JC4832W535 profile while keeping esp32s3 default
2026-03-01 Switch to BNO08x compass and align main compass math
2026-03-01 Add on-device HIL simulation loop and SIM BLE commands
2026-04-24 Refactor BLE live protocol and NH02 smoke flow
2026-04-24 Remove legacy motor PID path
2026-04-24 Harden stepper idle handling
2026-04-24 Harden GPS UART watchdog timers
2026-04-24 Handle settings commit failures
    [Settings.h]
2026-04-24 Isolate motor mode state
2026-04-24 Harden drift monitor inputs
    [DriftMonitor.h]
2026-04-24 Keep supervisor failsafes fail closed
    [AnchorSupervisor.h]
2026-04-24 Harden BLE live frame scaling
2026-04-24 Harden telemetry cadence timers
2026-04-24 Harden simulation badge timer
2026-04-24 Harden GPS UART watchdog timing
2026-04-24 Harden BNO RVC frame validation
2026-04-24 Harden motor auto thrust inputs
2026-04-24 Harden stepper idle release timing
2026-04-24 Fail closed GNSS quality gate
    [GnssQualityGate.h]
2026-04-25 Floor GPS UART watchdog intervals
2026-04-25 Keep failsafe stop path single-owned
    [RuntimeMotion.h]
2026-04-25 Decouple anchor supervisor from Arduino
2026-04-25 Reject padded BLE live frames
2026-04-25 Tighten Flutter live frame decoding
2026-04-25 Extract Flutter BLE device matching
2026-04-25 Tighten Android smoke telemetry criteria
2026-04-25 Filter Flutter BLE scans by service
2026-04-25 Tighten Flutter GATT UUID discovery
2026-04-25 Throttle Flutter BLE RSSI reads
2026-04-25 Reset HIL sensor heading baseline
    [HilSimRunner.h]
2026-04-25 Extract HIL error histogram
    [HilSimRunner.h]
2026-04-25 Extract HIL actuator capture
2026-04-25 Extract HIL sensor hub
2026-04-25 feat: add compass calibration and CI artifacts
2026-04-26 Add powered bench checklist
2026-04-26 Add brushed motor sim dynamics
2026-04-26 Add anchor jog UI and steering sim
2026-04-26 Add protected water power log
2026-04-26 Prepare pre-powered validation gates
2026-04-26 Tighten water test documentation
2026-04-26 Add brushed motor driver intake gate
2026-04-26 Add wave chop sensor metrics
2026-04-26 Add ground trike CAD export workflow
    [boatlock_ground_trike.FCStd, boatlock_ground_trike.scad, deck_plate.stl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]
2026-04-27 Stabilize bench diagnostics and SD logging
    [HilSimRunner.h, RuntimeBleLiveFrame.h, Settings.h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]
2026-04-27 Switch bench steering to DRV8825 service workflow
2026-04-27 Fix stepper gear ratio settings
    [BleCommandHandler.h, RuntimeBleLiveFrame.h, Settings.h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]
2026-04-28 Fix GitHub OTA BLE upload path
    [main.cpp]
